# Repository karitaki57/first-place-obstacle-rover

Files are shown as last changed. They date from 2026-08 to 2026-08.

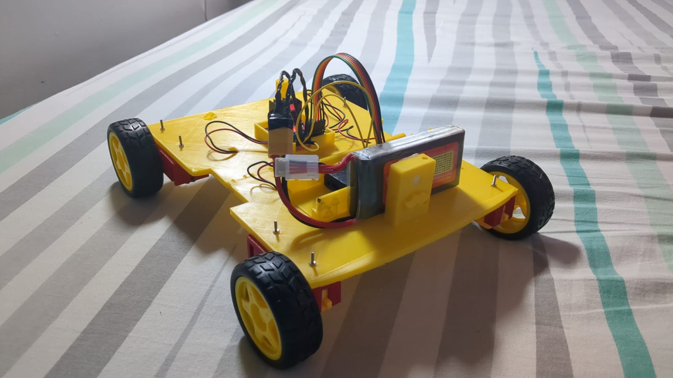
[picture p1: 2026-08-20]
media/IMG-20260818-WA0007.jpg

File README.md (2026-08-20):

HOW THE CAR WORKS

The code and wiring are in the same folder

This section explains the complete working of the ROVER — a 4WD Bluetooth-controlled competition RC car — from the moment a command is sent on the mobile app to the wheels physically moving.

Signal flow:

Mobile App (Bluetooth RC Controller)
        ↓
Bluetooth Classic (ESP32 BluetoothSerial, device name "ROVER")
        ↓
ESP32 Dev Board
        ↓
L298N Motor Driver
        ↓
4x TT Gear Motors (2 left, 2 right)
        ↓
Wheels
        ↓
Car Movement

Power flow:

3S 11.1V LiPo Battery
        ↓
L298N Motor Driver (motor power input)
        ↓
4x TT Gear Motors

3S 11.1V LiPo Battery
        ↓
L298N Onboard 5V Regulator
        ↓
ESP32 Dev Board

1. MOBILE APP CONTROLLER

The car is driven using the Bluetooth RC Controller Android app. The app connects to the ESP32 over Bluetooth Classic and sends single-character ASCII commands whenever the user presses a control button.

- Movement commands: F (forward), B (backward), L (left), R (right), S (stop)
- Speed commands: the digits 0–9 and q each select a fixed PWM speed level, sent as a single character before or during driving
- Each button press on the app transmits one character over the Bluetooth serial link; there is no complex packet structure — just a raw character stream
- The app does not send continuous analog data (no joystick-style variable steering); direction and speed are two independent, discrete command types

2. BLUETOOTH COMMUNICATION

Bluetooth communication is handled entirely through the ESP32's built-in Bluetooth Classic (SPP) stack, using the Arduino BluetoothSerial library.

- On boot, the ESP32 starts Bluetooth under the device name ROVER (serialBT.begin("ROVER"))
- The phone pairs with and connects to this ROVER Bluetooth device using the Bluetooth RC Controller app
- In the main loop, the ESP32 continuously checks serialBT.available() — as soon as a byte is waiting, it reads it into a char variable (btSignal)
- Each received character is compared against a set of known commands ('F', 'B', 'L', 'R', 'S', and '0'–'9'/'q') to decide what action to take
- There is no acknowledgment/handshake protocol — it's a simple one-directional command stream from phone to ESP32

3. ESP32

The ESP32 dev board is the brain of the car. It is the only microcontroller in the system and is responsible for:

- Receiving raw command characters through Bluetooth Classic
- Interpreting each character as either a movement command or a speed command
- Maintaining the current Speed variable (default 100, adjustable via commands 0–9/q, up to 255)
- Generating the correct digital direction signals (IN1–IN4) for the L298N
- Generating the correct PWM signals (via ledcWrite) for motor speed
- Running two independent PWM channels using the ESP32's LEDC hardware PWM peripheral, at 5 kHz with 8-bit resolution (0–255)

The ESP32 does not drive the motors directly — it only outputs low-power logic-level control signals to the L298N.

Pin mapping used in the code:

Function                          GPIO Pin     
PWM speed — Motor A (right side)  GPIO 14 (enA)
PWM speed — Motor B (left side)   GPIO 32 (enB)
Motor A direction IN1             GPIO 27      
Motor A direction IN2             GPIO 26      
Motor B direction IN3             GPIO 25      
Motor B direction IN4             GPIO 33      
4. MOTOR DRIVER — L298N

The ESP32's GPIO pins can only supply a few milliamps at 3.3V — nowhere near enough to spin gear motors. The L298N dual H-bridge motor driver sits between the ESP32 and the motors to solve this.

- The L298N receives low-power control signals from the ESP32: two direction pins per channel (IN1/IN2 for Motor A, IN3/IN4 for Motor B) and one PWM enable pin per channel (enA, enB)
- Separately, it receives high-power battery input directly from the 3S 11.1V LiPo on its main power terminals
- Internally, each H-bridge channel uses the IN1/IN2 (or IN3/IN4) logic levels to route battery current through the motor windings in one direction or the other, which is how direction (forward/reverse) is controlled
- The PWM signal on enA/enB switches the H-bridge output on and off rapidly (5 kHz), so the average voltage delivered to the motor — and therefore its speed — is proportional to the PWM duty cycle set by ledcWrite(channel, Speed)
- The L298N's onboard 5V regulator taps off the battery input and separately powers the ESP32, so the same battery feeds both the high-power motor side and the low-power logic side

This clearly separates the control path (ESP32 → IN1–IN4 + PWM, low power) from the power path (LiPo → L298N → motors, high power).

5. MOTORS — TT GEAR MOTORS (X4)

The car uses four TT gear motors, wired in a left/right pair configuration to the L298N's two channels:

- 2 motors (right side) wired in parallel to Motor A output (IN1/IN2, PWM on enA)
- 2 motors (left side) wired in parallel to Motor B output (IN3/IN4, PWM on enB)

Each TT gear motor is a brushed DC motor with an integrated gearbox that reduces the motor's raw RPM in exchange for higher torque, which is what allows the car to move a 3D-printed chassis and handle obstacles rather than just spinning its wheels.

- The L298N delivers switched DC current to each motor pair based on the IN pin states and PWM duty cycle
- Inside each motor, this current passes through the armature windings, which generates a magnetic field that interacts with the motor's permanent magnets, producing rotational torque on the output shaft
- The gearbox output shaft is directly connected to a wheel hub, so motor rotation is transferred straight into wheel rotation
- Because the two motors on each side are wired in parallel to the same channel, they always spin together at the same speed and direction — the car has two independently controllable drive sides (left side and right side), not four independently controlled wheels

6. MOVEMENT LOGIC

There is no steering servo — this is a differential (skid-steer) drive 4WD car. Turning is achieved purely by driving the left-side and right-side motor pairs at different directions/speeds relative to each other, not by turning the wheels.

FORWARD (F)

Mobile App sends 'F'
→ Bluetooth → ESP32 receives 'F'
→ ESP32 calls forward():
     IN1=HIGH, IN2=LOW   (right side forward)
     IN3=LOW,  IN4=HIGH  (left side forward)
     PWM = current Speed on both channels
→ L298N drives both motor pairs forward
→ Wheels spin forward
→ Car moves forward

BACKWARD (B)

Mobile App sends 'B'
→ ESP32 calls backward():
     IN1=LOW,  IN2=HIGH  (right side reversed)
     IN3=HIGH, IN4=LOW   (left side reversed)
→ Both motor pairs spin in reverse
→ Car moves backward

LEFT (L)

Mobile App sends 'L'
→ ESP32 calls left():
     IN1=HIGH, IN2=LOW   (right side forward)
     IN3=HIGH, IN4=LOW   (left side reversed relative to its forward wiring)
→ Right-side wheels and left-side wheels spin in opposite senses
→ Car pivots/turns left

RIGHT (R)

Mobile App sends 'R'
→ ESP32 calls right():
     IN1=LOW,  IN2=HIGH  (right side reversed)
     IN3=LOW,  IN4=HIGH  (left side forward relative to its forward wiring)
→ Right-side and left-side wheels spin in opposite senses (mirrored from LEFT)
→ Car pivots/turns right

STOP (S)

Mobile App sends 'S'
→ ESP32 calls stopMotors():
     PWM on both channels set to 0
     IN1=LOW, IN2=LOW, IN3=LOW, IN4=LOW
→ Both motor pairs de-energized
→ Car stops

SPEED CONTROL
Speed is controlled by the ESP32's hardware PWM (LEDC peripheral, 5 kHz, 8-bit resolution) on the enA/enB pins. Sending a digit 0–9 or q updates the Speed variable to a preset value between 100 and 255, which is then applied via ledcWrite() the next time a movement command runs. Higher PWM values mean the H-bridge output is "on" for a larger fraction of each cycle, so more average voltage — and more speed — is delivered to the motors.

7. POWER SYSTEM

                 3S 11.1V LiPo Battery
                          │
            ┌─────────────┴─────────────┐
            ▼                           ▼
      L298N motor input         L298N onboard 5V regulator
            │                           │
            ▼                           ▼
     4x TT Gear Motors                ESP32
     (2 right / 2 left)          (logic + Bluetooth)

- The 3S 11.1V LiPo is the single power source for the entire car
- It connects directly to the L298N's high-voltage input terminals, which supply the motors
- The L298N's onboard 5V linear regulator steps the 11.1V battery voltage down to a stable 5V, which powers the ESP32 — no separate buck converter is used
- Voltage regulation is necessary because the ESP32 is only rated for 5V (VIN) / 3.3V (logic) input; feeding it 11.1V directly would destroy the board
- This means motor power and logic power come from the same battery but are cleanly separated after the L298N — motor current spikes (e.g. from stalling against an obstacle) are isolated from the ESP32's regulated 5V rail

8. SOFTWARE WORKING

1. ESP32 boots and starts the serial monitor at 115200 baud
2. serialBT.begin("ROVER") initializes Bluetooth Classic and advertises the device as ROVER
3. GPIO pins for enA, enB, IN1–IN4 are configured as outputs
4. Two LEDC PWM channels are set up (5 kHz, 8-bit) and attached to enA and enB
5. stopMotors() is called once at startup so the car begins in a safe, stopped state
6. The mobile app connects to ROVER over Bluetooth
7. In loop(), the ESP32 continuously polls serialBT.available()
8. When a character arrives, it's read into btSignal and printed to the serial monitor for debugging
9. If btSignal is a digit ('0'–'9') or 'q', the Speed variable is updated to the corresponding preset value
10. If btSignal matches 'F', 'B', 'L', 'R', or 'S', the corresponding function (forward(), backward(), left(), right(), stopMotors()) is called
11. That function sets the IN1–IN4 direction pins and writes the current Speed value to both PWM channels via ledcWrite()
12. The L298N responds to the new pin states, driving the motors accordingly, and the wheels/car move
13. The loop repeats indefinitely, waiting for the next Bluetooth character

9. COMPLETE SYSTEM DIAGRAM

            ┌──────────────────────────┐
            │  Bluetooth RC Controller │
            │        (Mobile App)      │
            └────────────┬─────────────┘
                          │
                    Bluetooth Classic
                     (device: ROVER)
                          │
                          ▼
            ┌──────────────────────────┐
            │          ESP32           │
            │      Main Controller     │
            └────────────┬─────────────┘
                          │
              Direction pins (IN1–IN4)
                + PWM (enA / enB)
                          │
                          ▼
            ┌──────────────────────────┐
            │       L298N Driver       │
            └──────────┬───┬───────────┘
                        │   │
              Motor A   │   │  Motor B
             (right side)   (left side)
                        ▼   ▼
              ┌───────────┐ ┌───────────┐
              │ 2x TT Gear│ │ 2x TT Gear│
              │  Motors   │ │  Motors   │
              └─────┬─────┘ └─────┬─────┘
                    ▼             ▼
                Right Wheels   Left Wheels
                    │             │
                    └──────┬──────┘
                           ▼
                     CAR MOVEMENT

Power:

             ┌──────────────────┐
             │ 3S 11.1V LiPo     │
             └─────────┬─────────┘
                        │
         ┌──────────────┴──────────────┐
         ▼                             ▼
   L298N Motor Input           L298N Onboard 5V Reg
         │                             │
         ▼                             ▼
  4x TT Gear Motors                  ESP32

10. MECHANICAL WORKING

- The chassis is a custom 3D-printed body, printed in two main parts (vision_robo_race_part_1, vision_robo_race_part_2) which are joined together with glue after printing to form the complete chassis
- A dedicated 3D-printed fan holder mounts a cooling fan directly onto/near the L298N, keeping the motor driver cool under sustained high-current draw during the obstacle course
- Each TT gear motor sits in a dedicated 3D-printed TT motor mount (printable with no supports needed), which is fastened to the chassis using M2 x 15mm screws
- All four TT gear motors are mounted to the chassis at fixed positions — two per side, each in its own printed mount — with their output shafts driving the wheel hubs directly
- Wheels are mounted directly on the gearbox output shafts of each TT motor
- The L298N, ESP32, and LiPo battery are mounted on the chassis body, positioned to keep the car's weight balanced across all four wheels for stable handling over obstacles
- Because there is no steering linkage, turning is purely electronic (differential drive) — a mechanically simpler and more robust system for an obstacle-course competition, since there are fewer moving parts that can jam or break on impact

11. WHY EACH COMPONENT IS USED

Component                             Purpose                                                                               Connected To                                   
ESP32 Dev Board                       Main controller — receives Bluetooth commands and generates motor control signals     Bluetooth (built-in), L298N (IN1–IN4, enA, enB)
Bluetooth RC Controller (Mobile App)  Sends driving and speed commands wirelessly                                           ESP32 via Bluetooth Classic                    
3S 11.1V LiPo Battery                 Main power source for the entire car                                                  L298N motor input + L298N onboard 5V regulator 
L298N Motor Driver                    Converts low-power ESP32 signals into high-power motor drive; regulates 5V for ESP32  ESP32 (control) + LiPo (power) + 4x TT motors  
TT Gear Motors (x4)                   Produce rotational movement, geared down for torque                                   L298N (2 per channel) + wheels                 
Wheels                                Convert motor rotation into vehicle movement                                          TT gear motor output shafts                    
3D-Printed Chassis/Parts              Mechanical structure holding all components together                                  Motors, wheels, ESP32, L298N, battery          
3D-Printed L298N Fan Holder           Mounts a cooling fan to prevent L298N overheating                                     L298N                                          
3D-Printed TT Motor Mount             Holds each TT gear motor to the chassis, fastened with M2 x 15mm screws               TT gear motors + chassis                       
12. COMPETITION RESULT

This car, ROVER, was designed, built, and competed in the Vision Robo Race — an obstacle-course racing competition held at Silicon Sphere, VIS, Sector 10, Dwarka, Delhi.

🏆 1st Prize — Vision Robo Race (Obstacle Course)

The car's 4WD differential-drive layout, L298N-based motor control with PWM speed adjustment, and 3D-printed chassis (including a dedicated fan mount to keep the motor driver cool) were built specifically to handle the demands of navigating an obstacle course, and the design was validated by taking first place in the competition.

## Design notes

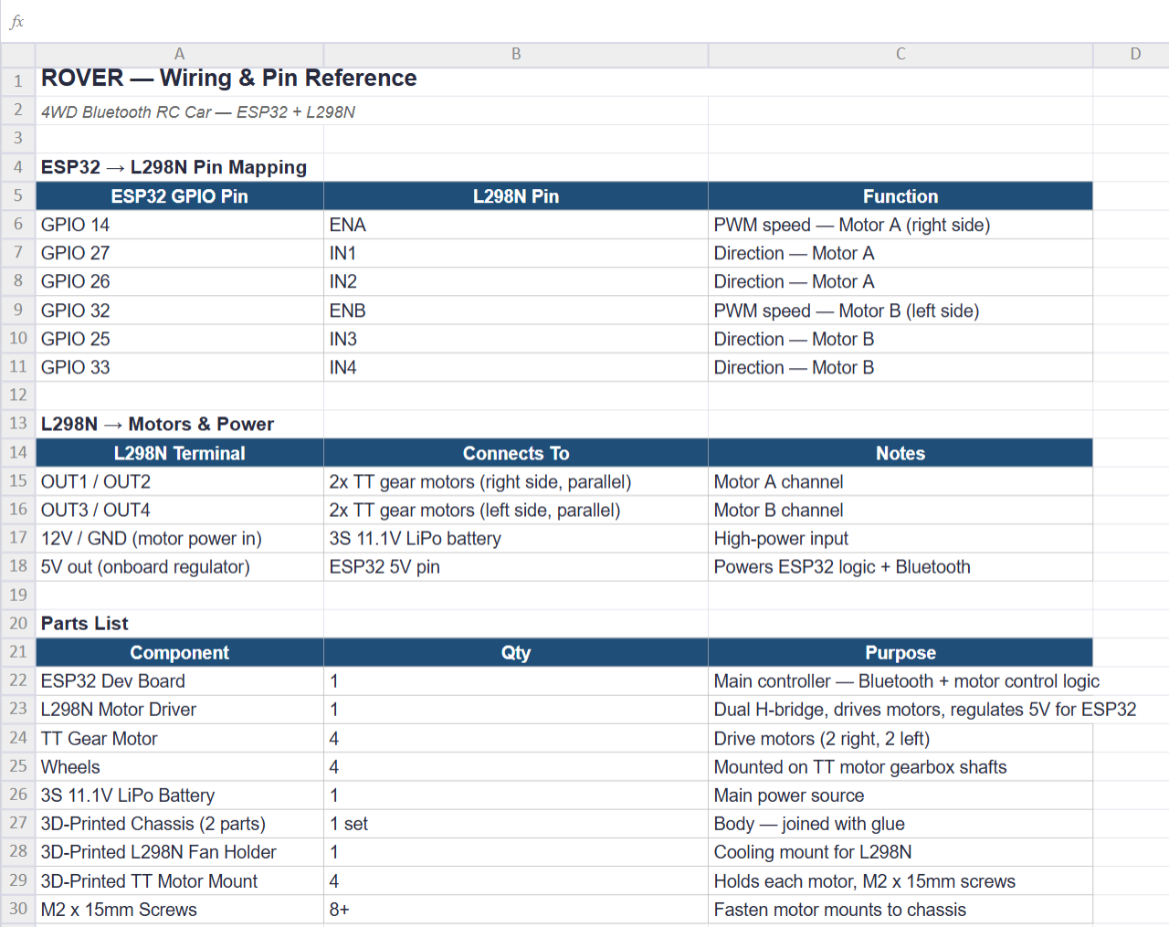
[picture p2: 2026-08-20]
code/Screenshot 2026-08-21 002832.png

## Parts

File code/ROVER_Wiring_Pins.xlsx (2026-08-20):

ROVER — Wiring & Pin Reference
4WD Bluetooth RC Car — ESP32 + L298N
ESP32 → L298N Pin Mapping
ESP32 GPIO Pin | L298N Pin | Function
GPIO 14 | ENA | PWM speed — Motor A (right side)
GPIO 27 | IN1 | Direction — Motor A
GPIO 26 | IN2 | Direction — Motor A
GPIO 32 | ENB | PWM speed — Motor B (left side)
GPIO 25 | IN3 | Direction — Motor B
GPIO 33 | IN4 | Direction — Motor B
L298N → Motors & Power
L298N Terminal | Connects To | Notes
OUT1 / OUT2 | 2x TT gear motors (right side, parallel) | Motor A channel
OUT3 / OUT4 | 2x TT gear motors (left side, parallel) | Motor B channel
12V / GND (motor power in) | 3S 11.1V LiPo battery | High-power input
5V out (onboard regulator) | ESP32 5V pin | Powers ESP32 logic + Bluetooth
Parts List
Component | Qty | Purpose
ESP32 Dev Board | 1 | Main controller — Bluetooth + motor control logic
L298N Motor Driver | 1 | Dual H-bridge, drives motors, regulates 5V for ESP32
TT Gear Motor | 4 | Drive motors (2 right, 2 left)
Wheels | 4 | Mounted on TT motor gearbox shafts
3S 11.1V LiPo Battery | 1 | Main power source
3D-Printed Chassis (2 parts) | 1 set | Body — joined with glue
3D-Printed L298N Fan Holder | 1 | Cooling mount for L298N
3D-Printed TT Motor Mount | 4 | Holds each motor, M2 x 15mm screws
M2 x 15mm Screws | 8+ | Fasten motor mounts to chassis

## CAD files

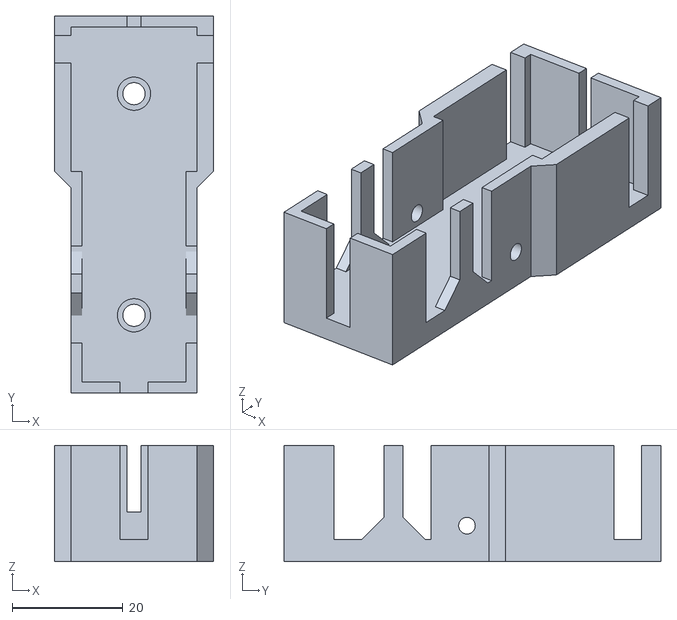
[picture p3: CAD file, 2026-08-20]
3d files (.stl , .3mf)/TT+motor+mount+-no+supports+needed.stl
28.7 x 68.0 x 21.0

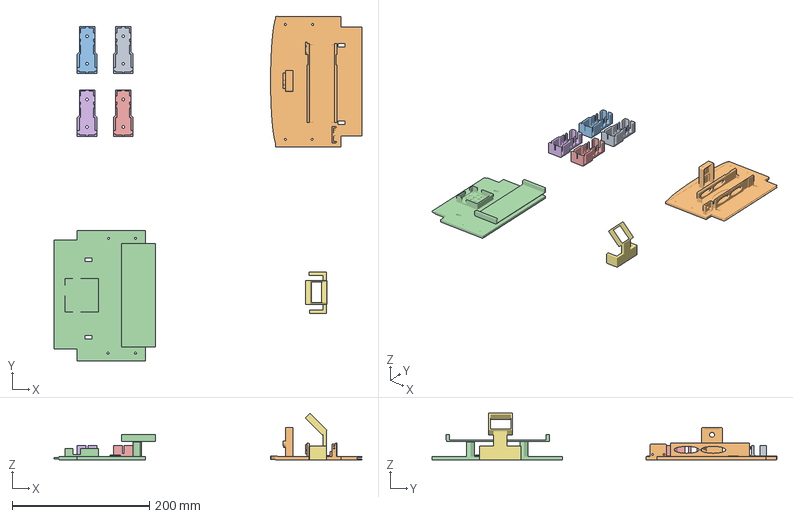
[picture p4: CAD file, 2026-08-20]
3d files (.stl , .3mf)/Vision robo race fan holder for l298n.3mf
448.1 x 502.1 x 67.8 mm
TT+motor+mount+-no+supports+needed.stl x 4
vision robo race part 1.stl
vision robo race part 2.stl
Vision robo race fan holder for l298n.stl

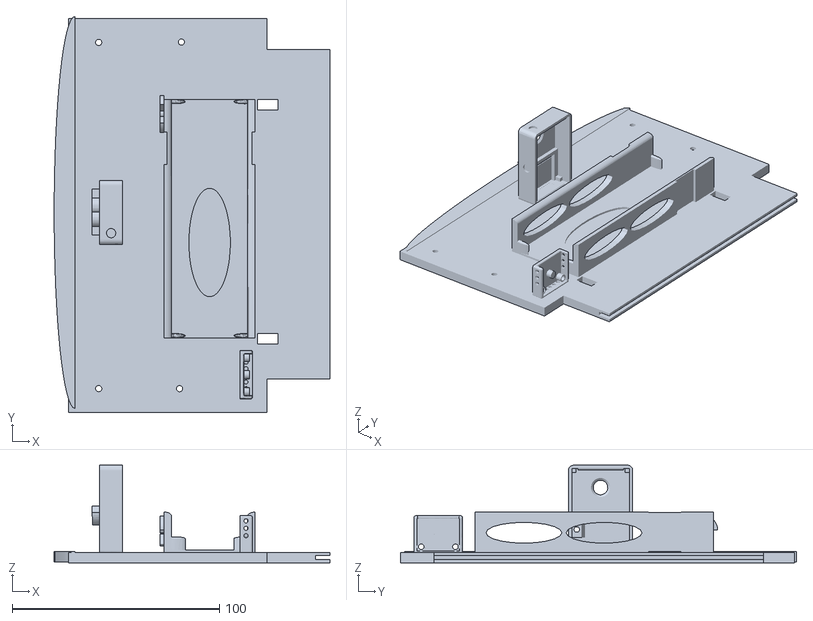
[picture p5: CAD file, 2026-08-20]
3d files (.stl , .3mf)/vision robo race part 1.stl
133.0 x 191.0 x 47.1

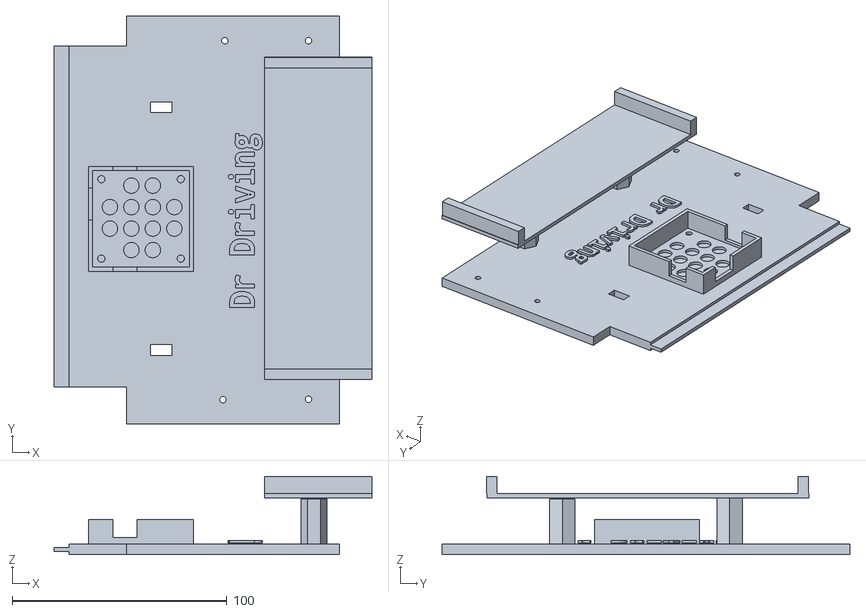
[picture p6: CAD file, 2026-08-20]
3d files (.stl , .3mf)/vision robo race part 2.stl
148.0 x 190.0 x 36.5

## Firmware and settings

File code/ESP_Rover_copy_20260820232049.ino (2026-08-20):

// ESP32 board version: 2.0.11
// Bluetooth Classic control

#include "BluetoothSerial.h"
#include <Arduino.h>

BluetoothSerial serialBT;

// Bluetooth signal
char btSignal;

// Initial speed
int Speed = 100;

// PWM channels
#define R 0
#define L 1

// ===============================
// YOUR MOTOR DRIVER WIRING
// ===============================

// PWM speed pins
int enA = 14;
int enB = 32;

// Motor A direction pins
int IN1 = 27;
int IN2 = 26;

// Motor B direction pins
int IN3 = 25;
int IN4 = 33;

// ===============================
// SETUP
// ===============================

void setup() {

  Serial.begin(115200);

  // Bluetooth name
  serialBT.begin("ROVER");

  // Motor pins
  pinMode(enA, OUTPUT);
  pinMode(enB, OUTPUT);

  pinMode(IN1, OUTPUT);
  pinMode(IN2, OUTPUT);

  pinMode(IN3, OUTPUT);
  pinMode(IN4, OUTPUT);

  // PWM setup
  ledcSetup(R, 5000, 8);
  ledcAttachPin(enA, R);

  ledcSetup(L, 5000, 8);
  ledcAttachPin(enB, L);

  // Start stopped
  stopMotors();

  Serial.println("================================");
  Serial.println("        ROVER READY");
  Serial.println("================================");
  Serial.println("Bluetooth: ROVER");
}

// ===============================
// LOOP
// ===============================

void loop() {

  while (serialBT.available()) {

    btSignal = serialBT.read();

    Serial.print("Command: ");
    Serial.println(btSignal);

    // ===========================
    // SPEED CONTROL
    // ===========================

    if (btSignal == '0') Speed = 100;
    if (btSignal == '1') Speed = 110;
    if (btSignal == '2') Speed = 120;
    if (btSignal == '3') Speed = 130;
    if (btSignal == '4') Speed = 140;
    if (btSignal == '5') Speed = 150;
    if (btSignal == '6') Speed = 180;
    if (btSignal == '7') Speed = 200;
    if (btSignal == '8') Speed = 220;
    if (btSignal == '9') Speed = 240;
    if (btSignal == 'q') Speed = 255;

    // ===========================
    // MOVEMENT
    // ===========================

    if (btSignal == 'B') {

      backward();

    }

    else if (btSignal == 'F') {

      forward();

    }

    else if (btSignal == 'L') {

      left();

    }

    else if (btSignal == 'R') {

      right();

    }

    else if (btSignal == 'S') {

      stopMotors();

    }
  }
}

// ===============================
// FORWARD
// ===============================

void forward() {

  ledcWrite(R, Speed);
  ledcWrite(L, Speed);

  // Motor A
  digitalWrite(IN1, HIGH);
  digitalWrite(IN2, LOW);

  // Motor B
  digitalWrite(IN3, LOW);
  digitalWrite(IN4, HIGH);
}

// ===============================
// BACKWARD
// ===============================

void backward() {

  ledcWrite(R, Speed);
  ledcWrite(L, Speed);

  // Motor A
  digitalWrite(IN1, LOW);
  digitalWrite(IN2, HIGH);

  // Motor B
  digitalWrite(IN3, HIGH);
  digitalWrite(IN4, LOW);
}

// ===============================
// LEFT
// ===============================

void left() {

  ledcWrite(R, Speed);
  ledcWrite(L, Speed);

  // Motor A forward
  digitalWrite(IN1, HIGH);
  digitalWrite(IN2, LOW);

  // Motor B forward
  digitalWrite(IN3, HIGH);
  digitalWrite(IN4, LOW);
}

// ===============================
// RIGHT
// ===============================

void right() {

  ledcWrite(R, Speed);
  ledcWrite(L, Speed);

  // Motor A backward
  digitalWrite(IN1, LOW);
  digitalWrite(IN2, HIGH);

  // Motor B backward
  digitalWrite(IN3, LOW);
  digitalWrite(IN4, HIGH);
}

// ===============================
// STOP
// ===============================

void stopMotors() {

  ledcWrite(R, 0);
  ledcWrite(L, 0);

  digitalWrite(IN1, LOW);
  digitalWrite(IN2, LOW);

  digitalWrite(IN3, LOW);
  digitalWrite(IN4, LOW);
}

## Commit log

2026-08-20 Create wiring
2026-08-20 Update README with code and wiring location
    Added information about code and wiring location.
